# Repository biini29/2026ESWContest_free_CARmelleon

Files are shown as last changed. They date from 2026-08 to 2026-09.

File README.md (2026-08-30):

# Smart Seat (Family Care) 🚗💺

> A ROS 2-based adaptive car seat system that automatically reshapes the backrest curve and adjusts seatbelt height to fit each occupant — from pregnant passengers to children old enough to have outgrown a car seat, to guests — sharing a single family vehicle.

**Embedded SW Contest 2026 — 자유공모 (Free Topic)** | Team **CAR멜레온**, Dongguk University, Dept. of Mechanical, Robot & Energy Engineering

**Team**
| Name | Role |
|---|---|
| **Sulbeen Min** (민설빈, Team Leader) | ROS 2 system integration, control logic, hardware bridge, calibration, Size Korea regression analysis |
| **Jaekyung Kim** (김재경) | Overall design & pin wiring, integrating existing nodes into the launch file, GitHub repository organization |
| **Bogyeom Cha** (차보겸) | Overall design (lead) & hardware wiring, assembly integration, GitHub repository organization |

> Full background, goals, usage scenarios, team role breakdown, and the complete development schedule are in [`docs/01_Project_Overview/`](./docs/01_Project_Overview/).

---

## 📂 소스코드 위치 (심사용 바로가기)

| 구분 | 경로 | 설명 |
|---|---|---|
| ROS 2 노드 (Python) | [`src/`](./src/) | 키패드·프로필 계산·시트/벨트 제어·아두이노 브릿지 5개 노드 |
| 아두이노 스케치 (C++) | [`arduino/smart_seat_mega/`](./arduino/smart_seat_mega/) | 리니어 액추에이터 5개 구동 + HC-SR04 초음파 측정 |
| 커스텀 메시지 | [`msg/TargetSeatProfile.msg`](./msg/TargetSeatProfile.msg) | 벨트 높이 + 액추에이터 목표 배열 |
| 실행 파일 | [`launch/smart_seat.launch.py`](./launch/smart_seat.launch.py) | 노드 5개 일괄 실행 |
| 데이터 | [`profiles.json`](./profiles.json), [`belt_home.json`](./belt_home.json) | 가족 프로필 · 다이나믹셀 홈 위치 |

> 데이터 흐름: `keypad_node → /body_data → profile_inference_node → /target_seat_profile → seat_controller_node / belt_controller_node → /motor_cmd → arduino_bridge_node`
> 초음파는 아두이노가 측정 → `arduino_bridge_node`가 `/ultrasonic_distance`로 중계 → `keypad_node` 수신.

---

## 📌 Overview

Smart Seat infers a rider's body profile — from height, weight, and pregnancy status — using an anthropometric regression model built on **Size Korea 8th survey data (n=5,092)**, then drives:

- **5 linear actuators** to reshape the backrest along a Gaussian curve centered on the lumbar apex (with a softened, lower curve for pregnant riders, based on ergonomics literature on lordosis and iliac artery compression risk), and
- **2 Dynamixel servo motors** to raise or lower the seatbelt anchor to shoulder height (or pelvic height in pregnant mode).

Riders select a saved family profile (A/B/C) or enter a custom height as a guest, via a 4×4 keypad + I2C LCD — or simply sit still for 3 seconds (long-press the guest key) and let an ultrasonic sensor estimate their height automatically. The whole pipeline — input → body model → actuator targets → motor motion — runs as a set of ROS 2 nodes on a Raspberry Pi, bridging to an Arduino Mega (linear actuators) and a U2D2 Power Hub Board (Dynamixel belt motors).

> 📖 더 자세한 문서는 [`docs/`](./docs/) 폴더를 참고하세요 — [프로젝트 개요](./docs/01_Project_Overview/), [설계](./docs/02_Design/), [하드웨어 부품 목록](./docs/03_Hardware/), [소프트웨어 아키텍처](./docs/04_Software/), [테스트 로그](./docs/05_Test/), [데모 자료](./docs/06_Demo/).

<!-- IMAGE: hero shot — 완성된 시트 전체 모습 (또는 작동 GIF), 파일명 예: docs/img/hero.jpg -->
<!-- ![Smart Seat](docs/img/hero.jpg) -->

## 📸 Image Checklist

아래 표에 해당하는 사진/영상을 찍어서 `docs/img/`(사진), `docs/cad/`(3D·2D 도면)에 넣고, 이 파일의 해당 `<!-- IMAGE -->` 주석 자리에 마크다운 이미지 태그로 바꿔주세요.

| # | 내용 | 종류 | 넣을 위치(이 파일 내) |
|---|---|---|---|
| 1 | 완성된 시트 전체 모습 (또는 작동 GIF) | 실물 사진/GIF | Overview 바로 아래 (hero) |
| 2 | 전체 조립 렌더 (등받이+벨트 결합) | 3D 렌더 | Hardware 섹션 |
| 3 | 배선 실물 사진 (아두이노·L298N·다이나믹셀·U2D2 연결부) | 실물 사진 | Hardware 섹션 |
| 4 | 키패드+LCD 클로즈업 | 실물 사진 | Hardware 섹션 |
| 5 | 리니어 액추에이터 5개 배치 클로즈업 | 실물 사진 | Hardware 섹션 |
| 6 | 벨트 릴/가이드레일 구조 | 3D 렌더 또는 실물 사진 | Hardware 섹션 |
| 7 | 헤드레스트 ㄱ자 브라켓 (초음파센서 마운트) | 3D 렌더 또는 실물 사진 | Hardware 섹션 |
| 8 | 2D 상세 도면 전체 | 2D CAD | `docs/cad/` 폴더에 파일만 넣기 (README엔 폴더 링크만) |

---

| | |
|---|---|
| **Platform** | Raspberry Pi 3 (ROS 2 Humble) + Arduino Mega |
| **Actuation** | 5x Linear Actuators (backrest) + 2x Dynamixel XL430-W250-T (seatbelt height) |
| **Input** | 4x4 matrix keypad + I2C LCD (family profiles + guest mode) |
| **Language** | Python (ROS 2 nodes), C/C++ (Arduino firmware) |
| **Communication** | ROS 2 topics · Serial/UART (Arduino) · U2D2 (Dynamixel Protocol 2.0) |

---

## 🏗️ System Architecture

```mermaid
graph LR
    K[keypad_node<br/>keypad + LCD, family profiles] -- /body_data --> P[profile_inference_node<br/>Size Korea regression + Gaussian curve]
    P -- /target_seat_profile --> S[seat_controller_node<br/>per-actuator timing control]
    P -- /target_seat_profile --> B[belt_controller_node<br/>Dynamixel position control]
    S -- /motor_cmd --> AB[arduino_bridge_node]
    AB -- Serial/UART --> AM[Arduino Mega]
    AM --> LA[5x Linear Actuators]
    B -- U2D2 / Protocol 2.0 --> DXL[2x Dynamixel XL430]
```

---

## 🧩 ROS 2 Nodes

### `profile_inference_node`
Converts height (+ weight, + pregnancy flag) into:
- a per-actuator backrest push profile, using a **Gaussian curve** centered on the lumbar apex (`sitting_height × 0.18`, or `× 0.12` and softened in pregnant mode) — modeling the cloth+foam surface as a continuous curve rather than 5 independent points, and
- a target seatbelt height (shoulder height `sitting_height × 0.80` in normal mode, a fixed pelvic target in pregnant mode), converted to Dynamixel ticks via an empirically calibrated ticks/mm ratio.

Sitting height is estimated from a linear regression fit to Size Korea 8th survey data (R² = 0.842).

### `seat_controller_node`
Drives the 5 linear actuators (no position encoders):
- Per-motor, per-direction speed constants (measured individually) convert a target displacement into a drive duration
- Threaded, simultaneous multi-actuator motion
- Reset sequence to re-home all actuators to a known baseline

### `belt_controller_node`
Drives the 2 Dynamixel seatbelt motors in **Extended Position Control Mode** (multi-turn):
- Loads a calibrated home position from `belt_home.json` and homes once at startup
- Converts target ticks (from `profile_inference_node`) into absolute Dynamixel goal positions
- Waits for actual arrival (position-stall detection) rather than a fixed timeout
- Ignores the shared reset signal — only the linear actuators reset on demand, since belt homing is comparatively slow

### `arduino_bridge_node`
Bridges ROS 2 and the embedded layer — subscribes to `/motor_cmd`, translates commands into the `M,<motor>,<dir>,<speed>` serial protocol, and forwards them to the Arduino Mega over UART.

### `keypad_node`
Scans a 4×4 matrix keypad (non-blocking), drives a 16x2 I2C LCD, and loads family profiles (name, height, pregnancy flag) from `profiles.json`. Profile buttons (A/B/C) publish a saved profile; a guest button enters free-form height entry with range validation. Long-pressing the guest button (3s) instead triggers an **ultrasonic auto-measurement**: an HC-SR04 sensor mounted above the seat measures the distance to the rider's head, converts it (via the 2:1 physical scale factor and the same Size Korea regression) into an estimated standing height, and either applies it directly or shows an out-of-range message if outside 130–185cm.

---

## 🔧 Hardware

| Component | Role |
|---|---|
| Raspberry Pi 3 | Runs ROS 2 Humble, all high-level nodes |
| Arduino Mega | Low-level PWM driving for 5 linear actuators |
| 5x Linear Actuators + L298N drivers | Backrest shape adjustment |
| 2x Dynamixel XL430-W250-T + U2D2 Power Hub Board | Seatbelt anchor height adjustment |
| 4x4 matrix keypad + I2C LCD (0x27) | Family profile selection / guest input |
| HC-SR04 ultrasonic sensor (mounted in a 3D-printed ㄱ-bracket above the seat) | Automatic height estimation on guest-key long-press |

USB device names are pinned via `udev` rules (`/dev/arduino_linear`, `/dev/belt_u2d2`) so port numbers no longer shift between reboots or reconnects.

<!-- IMAGE: 배선도(회로 사진 또는 3D 조립 렌더), 개별 하드웨어 클로즈업 — 위 Image Checklist #2~7 참고 -->
<!-- ![Wiring](docs/img/wiring.jpg) -->
<!-- ![Assembly](docs/cad/assembly_render.png) -->
<!-- 2D 상세 도면 전체는 docs/cad/ 폴더 참고 -->

---

## 🚀 How to Run

```bash
# 1. Build the workspace
cd ~/ros2_ws
colcon build --packages-select smart_seat
source install/setup.bash

# 2. Launch the full system
ros2 launch smart_seat smart_seat.launch.py

# 3. (Example) Send a body profile directly, bypassing the keypad
ros2 topic pub /body_data geometry_msgs/msg/Point "{x: 178.0, y: 65.0, z: 0.0}" --once
# x = height (cm), y = weight (kg), z = 1.0 for pregnant mode
```

---

## 🐛 Troubleshooting Log

Real problems hit and solved during development:

**Repeated stepper driver failures (NEMA17 + DRV8825)**
Symptom: driver board smoke, melted jumper wires on GND and VMOT lines, twice. Root cause never fully confirmed (suspected VREF/current-limit misconfiguration). Fix: abandoned the stepper approach entirely and switched to Dynamixel XL430 servos with a U2D2 Power Hub Board, which have built-in current limiting.

**스텝모터 구동 시 라즈베리파이 저전압 증상**
Symptom: intermittent USB dropouts, `Undervoltage detected!` in `dmesg`, occurring specifically while driving the stepper motors (NEMA17 + DRV8825). Diagnosis: not a PD-adapter/Pi incompatibility — the same adapter (PD/fixed-5V dual capable) worked fine before and after; the undervoltage coincided with the stepper motors' high current draw pulling down the shared rail. Fix: the symptom disappeared entirely once the stepper motors were replaced with Dynamixel servos — no separate power adapter swap was needed.

**Belt tick-to-mm ratio looked wildly nonlinear**
Symptom: identical tick commands produced very different real-world displacements across trials; initially suspected reel slip or layer-diameter growth from overlapping string winds. Root cause: the test script only observed motion for a fixed 4–6 second window and force-cut torque before large moves had actually finished — an artifact of the test harness, not the mechanism. Fix: rewrote the test/move scripts to wait for actual arrival (position-stall detection) instead of a fixed timeout.

**USB port numbers (`/dev/ttyUSB0/1/2`) kept shifting**
Symptom: recurring `could not open port` errors across both the Arduino and the Dynamixel U2D2 whenever a device was reconnected or the Pi rebooted. Fix: added `udev` rules keyed on each device's USB vendor/product ID and serial number, giving them fixed symlink names (`/dev/arduino_linear`, `/dev/belt_u2d2`).

**Physical motor position swap (linear actuators)**
Symptom: actuator at the 150mm (lumbar) mounting position was actually wired to Arduino motor channel 2, and vice versa for channel 1 — a wiring/assembly mix-up discovered after calibration. Fix: rather than re-wiring, added a `MOTOR_MAP` lookup in `seat_controller_node` so logical actuator positions map to the correct physical channel in software.

**Belt position drifted after repeated manual repositioning**
Symptom: after physically moving the belt motors by hand during debugging, the seat would move to unexpected/out-of-range positions on the next command. Root cause: the saved `belt_home.json` reference no longer matched the true physical home. Fix: re-homed by hand, re-captured the current raw encoder position into `belt_home.json`.

**Race condition on repeated button presses**
Symptom: pressing the same profile button (e.g., B) repeatedly sent the belt to a different position each time. Root cause: each press spawned a new thread that concurrently wrote to the same Dynamixel `GroupSyncWrite` object. Fix: added a `threading.Lock` around each belt move so commands execute strictly in sequence.

**Belt appeared to not return home after being idle for days**
Symptom: on restart after a multi-day gap, the belt controller logged a normal-looking homing sequence but the belt didn't visibly move. Root cause: Dynamixel torque had been left disabled (torque is cut on node shutdown) — the controller was correctly commanding a position, but with no torque applied the motor simply couldn't act on it. Fix: re-enabled torque before testing; confirmed homing works correctly once torque is on.

**Keypad extension cable produced spurious key presses**
Symptom: right after startup, the 'D' key would register as pressed with no one touching it, and only the rightmost column / bottom row of keys (A/B/C/D, `.`/0/E) behaved erratically while number keys were fine. Diagnosis: scanning each row while it was driven HIGH and watching for unexpected column reads (with nothing pressed) showed random, shifting ghost signals across multiple columns — consistent with a loose connection rather than a fixed miswire. Root cause: the keypad extension cable's connector was making intermittent contact. Fix: tightened the connector; the cable is kept physically undisturbed during demos as a precaution.

<!-- 개발하면서 겪는 문제들을 여기에 계속 기록하세요. -->

---

## 📄 License

This project is licensed under the [MIT License](./LICENSE).

Third-party CAD assets (Dynamixel, linear actuator, HC-SR04 vendor/community models) used under their respective licenses — see [`docs/02_Design/mechanical/3D_model/partial_component/third_party/README.md`](./docs/02_Design/mechanical/3D_model/partial_component/third_party/README.md) for full attribution.

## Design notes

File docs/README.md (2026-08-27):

# 문서 목차

가변형 스마트시트(Family Care) 프로젝트의 전체 개발 문서입니다. 아래 순서대로 읽으시면 프로젝트를 처음부터 이해할 수 있습니다.

## 📋 [01_Project_Overview](./01_Project_Overview/)
개발 배경, 목표, 사용 시나리오, 팀 구성, 전체 개발 일정을 담고 있습니다. **여기부터 읽으시는 걸 추천합니다.**

- [01_Background_and_Goal.md](./01_Project_Overview/01_Background_and_Goal.md) — 개발 배경 및 목표
- [02_System_Architecture_Overview.md](./01_Project_Overview/02_System_Architecture_Overview.md) — 전체 시스템 구성 요약
- [03_Team_Roles_and_Schedule.md](./01_Project_Overview/03_Team_Roles_and_Schedule.md) — 팀원 역할 및 개발 일정

## 🎨 [02_Design](./02_Design/)
전기·기구 설계 문서입니다.

- [electrical/](./02_Design/electrical/) — 전원 계통도, 전체 결선도, Arduino/L298N 핀맵
- [mechanical/](./02_Design/mechanical/) — 3D 모델(조립도, 부품별 CAD), third-party CAD 출처

## 🔧 [03_Hardware](./03_Hardware/)
사용한 하드웨어 부품 목록(BOM)과 실제 구매 비용을 정리했습니다.

## 💻 [04_Software](./04_Software/)
ROS 2 소프트웨어 구조와 핵심 알고리즘 문서입니다.

- [01_Ros_Architecture.md](./04_Software/01_Ros_Architecture.md) — 노드 구성, 토픽/메시지 구조
- [02_Seat_Control_Algorithm.md](./04_Software/02_Seat_Control_Algorithm.md) — 회귀식, 가우시안 곡선, 벨트 계산식
- [03_Arduino_Ros_Protocol.md](./04_Software/03_Arduino_Ros_Protocol.md) — Arduino ↔ ROS 2 시리얼 프로토콜

## 🧪 [05_Test](./05_Test/)
개발 중 발생한 장애요인과 해결방안을 정리한 트러블슈팅 로그입니다.

## 🎬 [06_Demo](./06_Demo/)
시스템 블록 다이어그램, 하드웨어 실물 사진, 시연 영상입니다.

---

## 관련 코드

- [`../src/`](../src/) — ROS 2 노드 5개 소스코드
- [`../launch/`](../launch/) — 전체 시스템 실행 launch 파일
- [`../msg/`](../msg/) — 커스텀 메시지 정의
- [`../scripts/`](../scripts/) — `keypad_node.py` 내 세 기능(게스트모드, 프로필관리, 초음파필터) 설명 문서

전체 프로젝트 개요는 저장소 최상위 [README.md](../README.md)를 참고하세요.

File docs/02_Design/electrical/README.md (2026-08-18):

# Electrical Subsystem — 개요

전원, 통신, 센서/액추에이터 배선을 다루는 전기 서브시스템 문서입니다. 상세 핀맵은 [`03_Pinout_Table.md`](./03_Pinout_Table.md), 전체 회로도는 [`전원계통도_및_전체_결선도.png`](./전원계통도_및_전체_결선도.png)를 참고하세요.

---

## 1. 전원 계통 (2개 독립 라인)

| 전원 | 대상 | 비고 |
|---|---|---|
| 5V 전원 어댑터 (다이소, 12V/5V 겸용) | Raspberry Pi 3 전용 | 12V SMPS 계통과 완전히 독립된 별도 전원선. 스텝모터 구동 중 저전압 증상이 있었으나 원인은 스텝모터 전류 소모였음(어댑터 자체 문제 아님) — 다이나믹셀 교체 후 해소 |
| 12V SMPS | L298N 드라이버 3개 + U2D2 Power Hub Board | 모터/서보 구동 전원, Pi/Arduino 로직 전원과 분리 |

**⚠️ 공통 접지(GND) 필수**: Raspberry Pi · Arduino Mega · L298N × 3 · 12V SMPS · U2D2의 GND는 모두 하나로 묶여야 합니다. 분리되어 있으면 시리얼 통신 오류나 센서 오작동의 원인이 됩니다.

---

## 2. 통신 계통

| 연결 | 방식 | 고정 장치명 | 비고 |
|---|---|---|---|
| Pi ↔ Arduino Mega | USB Serial, 115200bps | `/dev/arduino_linear` | `M,모터,방향,속도` 프로토콜 |
| Pi ↔ U2D2 | USB, Dynamixel Protocol 2.0, 1,000,000bps | `/dev/belt_u2d2` | GroupSyncWrite로 동시 제어 |
| Pi GPIO ↔ 키패드 4x4 | 폴링 방식(50ms) | — | Row 4핀 OUT, Col 4핀 IN(PUD_DOWN) |
| Pi GPIO(I2C) ↔ LCD | I2C, 주소 0x27 | — | SDA=GPIO2, SCL=GPIO3 |
| Pi GPIO ↔ HC-SR04 | TRIG/ECHO 폴링 | — | TRIG=GPIO23, ECHO=GPIO24 |

### USB 장치명이 고정된 이유

USB 재연결·재부팅마다 `/dev/ttyUSB0/1/2` 번호가 바뀌어 연결 실패가 반복되던 문제를, `udev` 규칙(장치의 USB Vendor/Product ID + 시리얼 번호 기준)으로 고정 심볼릭 링크를 부여해 해결했습니다. 코드에서는 `/dev/ttyUSB*`가 아니라 반드시 `/dev/arduino_linear`, `/dev/belt_u2d2`를 참조합니다.

---

## 3. 주의사항

### HC-SR04 ECHO 핀 레벨시프트

HC-SR04의 ECHO 출력은 5V인데, Raspberry Pi GPIO는 3.3V 입력 기준입니다. **ECHO를 GPIO에 직결하면 장기적으로 GPIO 손상 위험이 있습니다.** 저항 분배(예: 1kΩ + 2kΩ) 또는 레벨시프터를 거치는 것을 권장하며, 현재 구성에서 이 부분을 확인이 필요합니다.

### Arduino Mega 스케치 관리

Arduino에는 리니어 액추에이터 전용 스케치가 항상 올라가 있어야 합니다. 개발 중 다른 테스트 스케치를 업로드한 뒤 리니어 전용 스케치로 되돌리지 않아 전체 시스템이 응답하지 않았던 사고가 있었습니다 — 스케치를 바꿔 테스트할 경우, 작업 종료 시 반드시 리니어 전용 스케치로 재업로드해야 합니다.

### 다이나믹셀 보드레이트

기본값(57600)이 아니라 **1,000,000bps**로 설정되어 있습니다. 다른 보드레이트로는 ping조차 응답하지 않습니다.

---

## 4. 관련 문서

- [`03_Pinout_Table.md`](./03_Pinout_Table.md) — Arduino/L298N 상세 핀맵
- [`전원계통도_및_전체_결선도_통합.md`](./전원계통도_및_전체_결선도_통합.md) — 통합 회로도
- [`03_Arduino_Ros_Protocol.md`](../../04_Software/03_Arduino_Ros_Protocol.md) — 시리얼 프로토콜 명세
- [`01_하드웨어_사용_부품_목록표.md`](../../03_Hardware/01_하드웨어_사용_부품_목록표.md) — 부품 목록(BOM)

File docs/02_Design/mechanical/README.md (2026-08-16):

## 1. 전체 구조 개요

본 프로젝트는 실제 차량용 컴포트 시트 메커니즘을 검증하기 위해 제작된 **2:1 축소 스케일 프로토타입**입니다. 실물 시트의 기하학적 형상과 기계적 동작 원리를 유지하면서, 부스 전시 규격 제약과 3D 프린터 출력 가능 범위를 고려하여 외형 및 동작 스트로크 비율을 50% 축소 적용하였습니다.

이 축소 모형을 통해 5개의 리니어 액추에이터를 활용한 등받이 요추(Lumber) 제어 및 다이나믹셀 기반의 능동형 안전벨트 장력 조절 메커니즘을 소형 공간 내에서 직관적으로 검증할 수 있습니다.

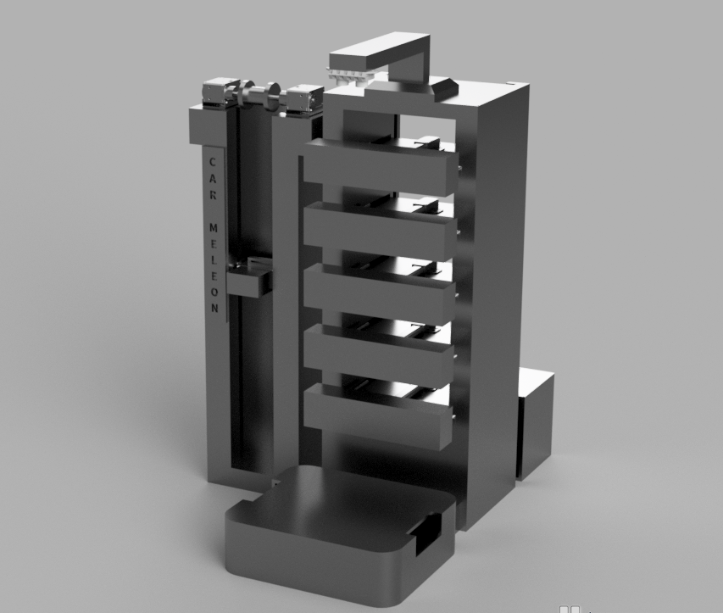
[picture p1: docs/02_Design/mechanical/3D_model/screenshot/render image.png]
전체 조립도


---

## 2. 등받이(백레스트) 구조

등받이 내부에는 총 5개의 리니어 액추에이터가 일정 간격으로 수직 배치되어 등받이 형상을 능동적으로 변형시킵니다. 액추에이터는 전용 고정 마운트 플레이트(`linear_motor_mount_plate`)에 구멍을 뚫어 나사(Screw) 체결 방식으로 고정하였으며, 백레스트 메인 외각 프레임(`backrest_outer_frame`)에 안정적으로 장착됩니다.

외부 표면은 착좌감과 실제 시트 질감을 구현하기 위해 프레임 및 액추에이터 구동부를 **천과 솜 커버**로 감싸 마감하였습니다.

- **액추에이터 결합 방식:** `linear_motor_mount_plate` 부품에 가공된 홀을 통해 리니어 액추에이터를 나사 고정
- **치수 및 간격 구현:** 
  - 하단 엉덩이 시트(시트 쿠션) 높이: **75mm**
  - 액추에이터 수직 위치: 시트 면 상단 기준 첫 번째 **160mm** 위치부터 **85mm 간격**으로 상단까지 5개 연속 배치 (160mm, 245mm, 330mm, 415mm, 500mm)
  - 각각의 액추에이터가 구동부 쉘(`backrest_shell`)을 인출/인입하여 세밀한 요추 지지 곡면 형성
- **연결 폴더:** [`Linear Moter Lumber Structure/`](./Linear%20Moter%20Lumber%20Structure/) 내부 자료 참고

| 항목 | 값 |
|---|---|
| 프레임 재질 | 3D 프린팅 및 메인 구조 프레임 |
| 액추에이터 고정 방식 | 마운트 플레이트(`linear_motor_mount_plate`) 타공 후 나사 체결 고정 |
| 등받이 곡면 재질 | 커스텀 프린팅 쉘 패널 (`backrest_shell`) + 천 & 솜 완충 커버 |

---

## 3. 안전벨트 릴/가이드레일 구조

탑승자의 체형 및 시트 상태 변형에 반응하여 벨트 장력을 능동적으로 제어하기 위해 2개의 ROBOTIS DYNAMIXEL XL430 모터가 적용되었습니다.

- **릴 메커니즘:** 다이나믹셀 모터의 출력 토크가 직접 설계한 커플링 부품인 **모터-샤프트 커넥터(`motor-shaft connecter`)** 및 **구동 샤프트(`belt_drive_shaft`)**를 거쳐 벨트 릴(`belt_drive_reel`)로 전달되어 회전하며 벨트(`belt`)를 정밀하게 권취/인출합니다.
- **주요 부품 구성:**
  - 모터 고정: `belt_motor_bracket`
  - 동력 전달 커스텀 설계: `belt_drive_shaft`, `motor-shaft connecter`
  - 벨트 가이드: `belt_guide` (벨트의 꼬임 방지 및 이송 경로 유지)
  - 외각 프레임: `seatbelt_outer_frame`
---

## 4. 헤드레스트 자리 — 초음파센서 ㄱ자 브라켓

탑승자의 앉은키(신장)를 실시간으로 측정하여 최적의 헤드레스트 위치 및 시트 제어 알고리즘을 수행하기 위해 초음파 센서(HC-SR04)가 설치됩니다.

- **설계 의도:** 센서를 상단에 안정적으로 지지하고 탑승자 머리 상단과의 거리를 수직 방향으로 정밀 측정하기 위한 ㄱ자 형상 브라켓 (`ultrasonic_sensor_bracket`) 활용
- **정확한 치수 연산:**
  - 센서 설치 높이: 바닥면 기준 프레임 높이 585mm + 브라켓 홀더 높이 80mm - 브라켓 오프셋 20mm= 645mm
  - 방석 기준 오차 보정 높이: **방석 면 기준 570mm** 고정 (상세 내용은 [`Seat_Control_Algorithm.md`](../../04_Software/Seat_Control_Algorithm.md) 4절 참고)
- **부품 위치:**
  - 센서 고정 프레임: [`ultrasonic_sensor_holder_frame.step`](3D_model/partial_component/custom/custom_stp/ultrasonic_sensor_holder_frame.step)
  - 센서 브라켓: [`ultrasonic_sensor_bracket.step`](3D_model/partial_component/third_party/third_party_stp/ultrasonic_sensor_bracket.step)

---

## 5. 파일 목록

| 파일/폴더 경로 | 설명 | 주요 포함 파일 형식 |
|---|---|---|
| [`3D_model/assemble/`](3D_model/assemble/) | 전체 조립 3D 모델 파일 | `.step`, `.stl` |
| [`3D_model/partial_component/custom/`](3D_model/partial_component/custom/) | 자체 설계 커스텀 파트 모음 | `custom_stp/` (`.step`), `custom_stl/` (`.stl`) |
| [`3D_model/partial_component/third_party/`](3D_model/partial_component/third_party/) | 외부 제조사 및 오픈소스 CAD 데이터 | `third_party_stp/` (`.step`), `third_party_stl/` (`.stl`) |
| [`3D_model/screenshot/`](3D_model/screenshot/) | 모델링 설계 및 렌더링 이미지 | `.png` |
| [`Linear Moter Lumber Structure/`](Linear%20Moter%20Lumber%20Structure/) | 등받이 액추에이터 배치 상세 구조 | - |

---

## 6. 설계 시 고려한 제약사항

- **2:1 스케일로 인한 제약 및 해결:**
  - 모터 및 액추에이터 등 기성 상용 부품은 50% 축소가 불가능하므로, 전용 마운트 플레이트(`linear_motor_mount_plate`) 및 모터 커넥터를 별도 설계하여 내부 간섭을 해결하고 메커니즘을 소형 프레임 안에 매립.
- **전시 부스 규격 (2m × 2m):**
  - 2:1 축소 설계를 통해 제어 박스(`control_box`) 포함 전체 모형이 소형화되어 2m × 2m 전시 공간 내에 여유 있게 배치 가능.
- **운반 및 조립 편의성:**
  - 시트 하단(`seat_bottom`), 백레스트 외각 프레임(`backrest_outer_frame`), 안전벨트 외각 프레임(`seatbelt_outer_frame`), 제어 박스(`control_box`)가 각 모듈별로 독립 분리 가능하도록 설계되어 있어 운반 및 현장 재조립이 용이함.

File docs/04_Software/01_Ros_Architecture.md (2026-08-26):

# ROS 2 Architecture

Smart Seat (Family Care)의 ROS 2 노드 구성, 토픽 흐름, 메시지 정의, 설계 결정을 정리한 문서입니다.

---

## 1. 노드 구성 개요

총 5개 노드가 하나의 launch 파일(`smart_seat.launch.py`)로 동시 실행됩니다.

| 노드 | 파일 | 역할 |
|---|---|---|
| `keypad_node` | `keypad_node.py` | 4x4 키패드 스캔, I2C LCD 출력, 가족 프로필 관리, 초음파 자동측정 |
| `profile_inference_node` | `profile_inference_node.py` | Size Korea 회귀식 + 가우시안 곡선 계산, 벨트 목표 산출 |
| `seat_controller_node` | `seat_controller_node.py` | 리니어 액추에이터 5개 시간기반 구동 |
| `belt_controller_node` | `belt_controller_node.py` | 다이나믹셀 2개 포지션 제어 |
| `arduino_bridge_node` | `arduino_bridge_node.py` | ROS 2 ↔ 아두이노 시리얼 브릿지 |

> **참고**: `sensor_bridge_node.py`는 압력센서(FSR) 등 실시간 피드백 확장을 위해 마련해둔 뼈대 코드로, 현재 launch 구성(5개 노드)에는 포함되지 않습니다. 향후 주행 중 자세 모니터링 등 확장 기능 개발 시 활용할 예정입니다.

---

## 2. 시스템 아키텍처 다이어그램

```mermaid
graph LR
    K[keypad_node] -- /body_data --> P[profile_inference_node]
    P -- /target_seat_profile --> S[seat_controller_node]
    P -- /target_seat_profile --> B[belt_controller_node]
    S -- /motor_cmd --> AB[arduino_bridge_node]
    AB -- "Serial (/dev/arduino_linear, 115200bps)" --> AM[Arduino Mega]
    AM --> LA[5x Linear Actuators via L298N x3]
    B -- "U2D2 (/dev/belt_u2d2, Protocol 2.0)" --> DXL[2x Dynamixel XL430]
```

---

## 3. 토픽 / 메시지 정리

| 토픽 | 메시지 타입 | 발행 | 구독 | 설명 |
|---|---|---|---|---|
| `/body_data` | `geometry_msgs/Point` | `keypad_node` | `profile_inference_node` | x=키(cm), y=몸무게(kg, 고정 65), z=임산부여부(0/1) |
| `/target_seat_profile` | `smart_seat/TargetSeatProfile` (커스텀) | `profile_inference_node` | `seat_controller_node`, `belt_controller_node` | 등받이 목표(actuator_mm[]) + 벨트 목표(belt_height_cm, 실제로는 필요틱수) |
| `/motor_cmd` | `std_msgs/String` | `seat_controller_node` | `arduino_bridge_node` | `M,모터번호,방향,속도` 형식 문자열 |

### `TargetSeatProfile.msg`

```
float32 belt_height_cm     # 벨트 필요 틱수 (필드명은 유지, 실제 단위는 틱)
float32[] actuator_mm      # 액추에이터 5개 목표 밀기량(mm)
```

- 리셋 신호는 `actuator_mm`의 모든 값이 0 이하일 때로 판단 (`belt_controller_node`는 이 신호를 무시하고 `seat_controller_node`만 반응)

---

## 4. 노드별 상세

### `keypad_node`
- 4x4 매트릭스 키패드(GPIO 폴링, 50ms 주기), I2C LCD(0x27)
- `profiles.json`에서 가족 프로필(A/B/C: 이름·키·임산부여부) 로드
- A/B/C: 저장된 프로필 즉시 적용
- D 짧게: 게스트 모드(숫자 직접입력)
- D 3초 롱프레스: 초음파 자동측정 모드
- `.`: 평상시 리셋 / 게스트모드 중 입력 없을 때 리셋+탈출 / 입력 중일 때 소수점
- 소프트웨어 안전장치: 4연속 디바운스, 다중 키 동시감지 시 무시(유령신호 방지), 부팅 1.5초 워밍업 무시구간, 게스트모드 오진입 시 프로필키 입력으로 자동 복구

### `profile_inference_node`
- Size Korea 8차 회귀식으로 앉은키 추정
- 가우시안 곡선으로 5개 액추에이터 각각의 밀기량 계산 (요추 곡선 + 헤드서포트, 둘 중 큰 값 채택)
- 벨트 목표(어깨/골반) 계산 후 2:1 스케일 + 실측 보정 적용, 틱수로 변환

### `seat_controller_node`
- 위치 센서 없음 → 모터별/방향별 실측 속도로 구동 시간 역산
- `MOTOR_MAP`으로 물리적으로 뒤바뀐 1·2번 액추에이터를 소프트웨어에서 보정
- 리셋 시 가장 오래 걸리는 모터 기준 + 여유시간만큼 전체 후진, 2번 모터만 추가 후진

### `belt_controller_node`
- Extended Position Control Mode(다회전)로 다이나믹셀 2개 구동
- `belt_home.json`에서 홈 포지션 로드, 노드 시작 시 1회 자동 홈 복귀
- 목표 도착까지 대기(포지션 스톨 감지) — 고정 타임아웃 방식은 재현성 문제로 폐기됨
- `threading.Lock`으로 동시 명령 충돌 방지 (연타 시 Race Condition 해결)
- 리셋 신호 무시 (벨트 리셋은 느려서 매번 반응하지 않음)

### `arduino_bridge_node`
- `/motor_cmd` 구독, `M,모터,방향,속도` 프로토콜로 변환하여 시리얼 전송

---

## 5. 설계 결정 근거

- **커스텀 메시지(`TargetSeatProfile`) 사용 이유**: 등받이(연속값 배열)와 벨트(단일값)를 한 번에 묶어 전달, 두 컨트롤러 노드가 같은 발행 시점의 목표를 일관되게 받도록 함
- **리셋 신호를 별도 토픽이 아닌 `/target_seat_profile`의 특수값(0 이하)으로 처리**: 새 토픽/서비스를 추가하지 않고 기존 파이프라인 재사용
- **벨트와 등받이 리셋 정책을 분리**: 벨트 홈 복귀가 상대적으로 느려, 매 리셋마다 실행하면 사용성이 떨어짐 — 노드 시작 시 1회만 자동 수행
- **USB 장치 이름 고정(`/dev/arduino_linear`, `/dev/belt_u2d2`)**: `udev` 규칙으로 포트 번호 유동성 문제 해결, 코드에서 하드코딩된 경로 안정성 확보



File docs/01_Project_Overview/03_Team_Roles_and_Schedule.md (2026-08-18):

# 팀원 역할 및 일정

## 1. 팀 구성

**팀명**: CAR멜레온 | 동국대학교 기계로봇에너지공학과

| 이름 | 역할 |
|---|---|
| **민설빈** (팀장) | ROS 2 시스템 통합, 제어 로직, 하드웨어 브릿지, 캘리브레이션, Size Korea 회귀분석 |
| **김재경** | 전체 설계 및 핀 연결, 기존 노드들을 launch 파일로 통합, GitHub 저장소 정리 |
| **차보겸** | 전체 설계(주도) 및 하드웨어 연결, 어셈블(통합) 파일 작업, GitHub 저장소 정리 |

## 2. 역할 분담 개요

- **하드웨어/메커니즘 설계**: 시트 구조, 리니어 액추에이터 배치, 다이나믹셀 벨트 릴 구조, 헤드레스트 자리 초음파센서 브라켓 CAD (주로 차보겸, 전체 설계 참여)
- **회로/전원 설계**: SMPS 배선, Arduino 핀맵, L298N 모터드라이버 회로 (김재경·차보겸 공동)
- **임베디드/ROS 소프트웨어**: 아두이노 펌웨어, ROS 2 노드, 통신 프로토콜, 캘리브레이션 (민설빈 중심)

## 3. 개발 일정

| 기간 | 단계 | 개발 내용 |
|---|---|---|
| 6/12 ~ 6/17 | 기획 | 아이디어 회의 |
| 6/18 ~ 6/20 | 기획 | 아이디어 구체화 및 개발 방향 수립 |
| 6/21 ~ 6/22 | 기획 | 주요 기능 선정 |
| 6/23 ~ 6/25 | 기획 | 개발 태스크 세분화 |
| 6/25 ~ 6/26 | 기획 | 개발계획서 작성 |
| 6/27 ~ 6/28 | 시스템 설계 | 전체 시스템 구성 설계 |
| 6/28 ~ 6/29 | 시스템 설계 | Raspberry Pi / Arduino 역할 분담 |
| 6/29 | 시스템 설계 | 사용 부품 선정 및 사양 조사 |
| 6/30 ~ 7/1 | 하드웨어 설계 | 허리 시트 및 Arduino 핀맵 설계 |
| 7/1 ~ 7/2 | 통신 설계 | Raspberry Pi-Arduino 통신 구성 |
| 7/2 ~ 7/4 | 제어 설계 | 실시간 피드백 제어 구조 확정 및 실측 회귀계수 반영 |
| 7/4 ~ 7/9 | 기구 개발 | 허리 시트 실물 출력 및 벨트 부분 설계 |
| 7/4 ~ 7/9 | ROS 2 개발 | ROS 2 노드 기본 구조 구현 |
| 7/10 ~ 7/14 | Arduino 개발 | Arduino 모터 제어 코드 작성 |
| 7/10 ~ 7/14 | 테스트 | 리니어 모터 개별 동작 테스트 |
| 7/14 ~ 7/15 | ROS 2 개발 | `/motor_cmd` 통신 구현 |
| 7/14 ~ 7/15 | ROS 2 개발 | ROS 2 Launch 통합 |
| 7/15 ~ 7/17 | ROS 2 개발 | 키패드 노드 구현 및 기능 완성 |
| 7/15 ~ 7/17 | Arduino 개발 | 벨트 구동 제어 코드 구현 |
| 7/18 ~ 7/19 | 하드웨어 개발 | LCD I2C 연결 및 동작 테스트 |
| 7/19 ~ 7/23 | 하드웨어 보완 | 하드웨어 구성 마무리 및 벨트 구동 모터 변경 |
| 7/24 ~ 7/25 | Arduino 개발 | 모터 변경에 따른 제어 코드 수정 |
| 7/25 ~ 7/27 | 시스템 통합 | 전체 하드웨어 및 ROS 2 시스템 통합 |
| 7/27 ~ 7/28 | 기능 추가 | 외관 정리 및 초음파 센서 기능 추가 |
| 7/28 ~ 7/29 | 테스트 | 실제 시트에서 리니어 모터 구동 테스트 |
| 7/29 ~ 7/30 | 검증 | 오류 및 안전성 테스트 |
| 7/31 ~ 8/3 | 개선 | 문제점 수정 및 시스템 성능 개선 |
| 8/4 ~ 8/6 | 검증 | 최종 통합 테스트 및 기능 검증 |
| 8/8 ~ 8/12 | 문서화 | GitHub 문서 및 개발 산출물 정리 |
| 8/14 ~ 8/19 | 발표 | 최종 시연 및 발표 준비 |

개발 일정 간트차트

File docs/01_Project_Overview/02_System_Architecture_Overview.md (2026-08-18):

# 전체 시스템 구성 요약

## 1. HW/SW 스택 요약

| 구분 | 구성 |
|---|---|
| 상위 제어기 | Raspberry Pi 3 (ROS 2 Humble) |
| 하위 제어기 | Arduino Mega |
| 프레임워크 | ROS 2 Humble, rclpy(Python) |
| 등받이 구동 | 리니어 액추에이터 5개 + L298N 드라이버 3개 |
| 안전벨트 구동 | Dynamixel XL430-W250-T 2개 + U2D2 Power Hub Board |
| 입력 | 4x4 매트릭스 키패드, HC-SR04 초음파 센서 |
| 출력 | I2C LCD 16x2 |
| 전원 | 12V SMPS(모터 계통), 12V/5V 겸용 어댑터(라즈베리파이 전용, 완전 독립 계통) |
| 통신 | USB Serial(Pi↔Arduino, 115200bps), USB(Pi↔U2D2, Dynamixel Protocol 2.0, 1,000,000bps), GPIO(키패드/LCD/초음파) |

상세 부품 목록은 [`03_Hardware/01_하드웨어_사용_부품_목록표.md`](../../03_Hardware/01_하드웨어_사용_부품_목록표.md) 참고.

## 2. 상위/하위 제어기 역할 분담

### Raspberry Pi (상위 제어기)
- ROS 2 노드 5개 전체 실행 (`keypad_node`, `profile_inference_node`, `seat_controller_node`, `belt_controller_node`, `arduino_bridge_node`)
- 체형 데이터 계산(회귀식, 가우시안 곡선)
- 키패드/LCD/초음파 센서 직접 제어 (GPIO)
- 다이나믹셀 직접 제어 (U2D2를 통한 Protocol 2.0 통신)
- Arduino에 시리얼로 모터 명령 전달

### Arduino Mega (하위 제어기)
- Raspberry Pi로부터 받은 `M,모터번호,방향,속도` 명령을 해석
- L298N 드라이버 3개를 통해 리니어 액추에이터 5개의 PWM 속도·방향 직접 제어
- 위치 피드백 센서가 없어, 모터별 실측 속도(mm/s) 기반 시간 제어로 위치를 추정

> 다이나믹셀(안전벨트)은 Arduino를 거치지 않고 Raspberry Pi가 U2D2를 통해 직접 제어한다 — 등받이(리니어)와 벨트(다이나믹셀)는 완전히 분리된 두 개의 구동 경로다.

## 3. 데이터 흐름 개요

```
입력(키패드/초음파) → 체형 데이터 계산 → 목표값 산출
                                              ├─→ 등받이 구동 (Pi → Arduino → L298N → 액추에이터5개)
                                              └─→ 벨트 구동 (Pi → U2D2 → 다이나믹셀2개)
```

더 상세한 노드/토픽 구조는 [`04_Software/01_Ros_Architecture.md`](../../04_Software/01_Ros_Architecture.md), 계산 알고리즘은 [`04_Software/02_Seat_Control_Algorithm.md`](../../04_Software/02_Seat_Control_Algorithm.md) 참고.

## 4. 상위 개념도

전체 기능 블록 흐름은 [`06_Demo/01_System_Block_Diagram.md`](../../06_Demo/01_System_Block_Diagram.md), 전기적 배선/전원 계통은 [`electrical/`](../electrical/) 폴더 참고.

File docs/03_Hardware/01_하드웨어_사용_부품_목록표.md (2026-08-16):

# 하드웨어 사용 부품 목록표 (BOM)

## 1. 컴퓨팅 / 제어

| 부품 | 수량 | 역할 | 구매처 | 단가 | 비고 |
|---|---|---|---|---|---|
| Raspberry Pi 3 | 1 | 메인 컨트롤러, ROS 2 Humble 실행 | 동국대 기계로봇에너지공학과 소모임 MAC 비품 | - | 5V 고정 전원 필요(PD 어댑터 비호환) |
| Arduino Mega | 1 | 리니어 액추에이터 저수준 제어 | 쿠팡 | 20,240원 | USB로 Pi와 연결 |

## 2. 등받이(리니어 액추에이터) 계열

| 부품 | 수량 | 역할 | 구매처 | 단가 | 비고 |
|---|---|---|---|---|---|
| 12V 리니어 액추에이터 | 5 | 등받이 형상 조절 (150/320/490/660/830mm 위치) | 알리익스프레스 | 25,300원 × 5 = 126,500원 | 스트로크 100mm, 부하 70N, 원격제어용 브래킷 포함 |
| L298N 모터 드라이버 | 3 | 액추에이터 5개 구동 (2+2+1) | 동국대 기계로봇에너지공학과 소모임 MAC 비품 | - | 3번 보드 B채널 미사용 |

## 3. 안전벨트(다이나믹셀) 계열

| 부품 | 수량 | 역할 | 구매처 | 단가 | 비고 |
|---|---|---|---|---|---|
| Dynamixel XL430-W250-T | 2 | 안전벨트 높이 조절 | 동국대 기계로봇에너지공학과 소모임 MAC 비품 | - | ID 2, 12 |
| U2D2 | 1 | Dynamixel ↔ USB 통신 컨버터 | 동국대 기계로봇에너지공학과 소모임 MAC 비품 | - | Protocol 2.0, 1,000,000bps |
| U2D2 Power Hub Board | 1 | Dynamixel 전원 분배 | 동국대 기계로봇에너지공학과 소모임 MAC 비품 | - | 12V 입력 |
| 웨이빙끈(이중직 30mm) | 1 | 안전벨트 본체 | 쿠팡 | 6,200원 | 릴에 감기는 벨트 재질 |
| 안전벨트 연장 클립 | 1 | 벨트 길이 조절/연결 | 쿠팡 | 3,000원 | |

## 4. 입력 / 출력

| 부품 | 수량 | 역할 | 구매처 | 단가 | 비고 |
|---|---|---|---|---|---|
| 4x4 매트릭스 키패드 | 1 | 가족 프로필 선택 / 게스트 입력 | 동국대 기계로봇에너지공학과 소모임 MAC 비품 | - | GPIO 폴링 |
| I2C LCD 16x2 | 1 | 상태 표시 | 동국대 기계로봇에너지공학과 소모임 MAC 비품 | - | PCF8574 백팩, 주소 0x27 |
| HC-SR04 초음파 센서 | 1 | 게스트 자동 신장 측정 | 동국대 기계로봇에너지공학과 소모임 MAC 비품 | - | TRIG=GPIO23, ECHO=GPIO24 |
| 저항(레벨시프트용) | - | HC-SR04 ECHO 5V→3.3V 전압분배 | 아두이노 스타터 키트 동봉품 | - | 브레드보드로 결선 |
| 브레드보드 | 1 | 저항/점퍼선 임시 결선 | 아두이노 스타터 키트 동봉품 | - | |

## 5. 전원

| 부품 | 수량 | 역할 | 구매처 | 단가 | 비고 |
|---|---|---|---|---|---|
| 전원 어댑터 (PD/고정 5V 겸용) | 1 | Raspberry Pi 전원 | 기존 보유 | - | 스텝모터 사용 시 저전압 증상 있었으나, 다이나믹셀 교체 후 문제없이 사용 중 (교체한 것 아님) |
| 12V SMPS | 1 | L298N ×3, U2D2 Power Hub 전원 | 쿠팡 | 21,000원 | 산업용 SMPS, HS 150W-12V (정격전류 약 12.5A) |
| 탈피 전원선 파워코드 케이블(3C) | 1 | SMPS 전원 입력선 | 쿠팡 | 6,200원 | |

## 6. 구조물

| 부품 | 수량 | 역할 | 구매처 | 단가 | 비고 |
|---|---|---|---|---|---|
| ㄱ자 브라켓 (3D 프린트) | 1 | 초음파 센서 하향 장착 | 자체 제작 | - | Bambu Lab PLA 필라멘트, 바닥 585mm+브라켓 60mm 위치 |
| 아크릴판 | 1 | 구조 보강/마운트 | 쿠팡 | 4,900원 | |
| 2:1 축소 모형 프레임 | 1 | 등받이/시트 기구 구조 | 자체 제작 | - | `mechanical/` 폴더 도면 참고 |

## 7. 배선 / 기타

| 부품 | 역할 | 구매처 | 비고 |
|---|---|---|---|
| USB 케이블 (Pi↔Arduino, Pi↔U2D2) | 데이터 통신 | - | udev로 `/dev/arduino_linear`, `/dev/belt_u2d2` 고정 |
| USB-A 포트 연결 케이블 | Pi 데이터/전원 연결 | 다이소 | 2,000원 |
| USB 포트 어댑터 | 포트 확장/변환 | 다이소 | 5,000원 |
| 점퍼선 일체 | GPIO/전원 배선 | 아두이노 스타터 키트 동봉품 | 모든 GND 공통 연결 필수 |
| 키패드 연장 케이블 | 키패드↔Pi 거리 확보 | - | 접촉 불량 이슈 있었음 — 커넥터 고정 상태 정기 점검 필요 |

---

## 구매 비용 요약

| 구분 | 금액 |
|---|---|
| 실구매 총액 (알리+쿠팡+다이소) | **195,040원** |
| 소모임(MAC) 비품 활용분 | 별도 구매 없음 (라즈베리파이, 다이나믹셀, U2D2, L298N, 키패드, LCD, HC-SR04 등 핵심 모듈 다수) |

> 스텝모터(NEMA17+DRV8825) 관련 자재는 소손 사고 이후 다이나믹셀로 전면 교체되어, 실제 사용 부품에서 제외했습니다. (자세한 경위는 `05_Test.md` 1번 항목 참고)

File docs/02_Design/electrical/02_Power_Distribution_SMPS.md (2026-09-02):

# Smart Seat System Power Distribution

본 문서는 스마트 시트 시스템의 전원 공급 및 분배 구조를 정리한다.

장치 간 물리적 연결은 `01_Wiring_Diagram.md`, GPIO 및 Arduino 제어 핀 정보는 `03_Pinout_Table.md`에서 관리한다.

---

## 1. 전체 전원 계통

스마트 시트 시스템의 전원은 크게 다음 3개의 계통으로 구성한다.

1. Raspberry Pi / 제어 계통
2. Linear Motor 구동 계통
3. DYNAMIXEL 구동 계통

```mermaid
flowchart TB

    P5["5V 전원"]
    PI["Raspberry Pi 3"]
    ARD["Arduino Mega 2560"]
    EXT["Arduino 확장보드"]
    US["HC-SR04"]

    SMPS["12V SMPS"]

    L1["L298N #1"]
    L2["L298N #2"]
    L3["L298N #3"]

    M1["Linear Motor 1"]
    M2["Linear Motor 2"]
    M3["Linear Motor 3"]
    M4["Linear Motor 4"]
    M5["Linear Motor 5"]

    DXP["DYNAMIXEL용<br/>별도 외부 전원"]
    HUB["U2D2 Power Hub"]

    DX1["DYNAMIXEL XL430-W250-T #1"]
    DX2["DYNAMIXEL XL430-W250-T #2"]

    P5 -->|"5V"| PI

    PI -->|"USB"| ARD
    ARD --> EXT
    EXT -->|"5V / GND"| US

    SMPS -->|"12V + GND"| L1
    SMPS -->|"12V + GND"| L2
    SMPS -->|"12V + GND"| L3

    L1 --> M1

    L2 --> M3
    L2 --> M4

    L3 --> M5
    L3 --> M2

    DXP --> HUB

    HUB --> DX1
    HUB --> DX2
```

> U2D2는 DYNAMIXEL 통신 인터페이스이므로 위 전원 흐름도에서는 구동 전원 계통과 분리하였다. U2D2의 실제 통신 결선은 `01_Wiring_Diagram.md`에서 관리한다.

---

## 2. 전원 계통 구분

```text
[1] Raspberry Pi / 제어 계통

5V 전원
   │
   ▼
Raspberry Pi 3
   │
   └── USB ──→ Arduino Mega 2560
                    │
                    ▼
              Arduino 확장보드
                    │
                    └──→ HC-SR04

[2] Linear Motor 구동 계통

12V SMPS
   │
   ├──→ L298N #1 ──→ Motor 1
   │
   ├──→ L298N #2 ──→ Motor 3 / Motor 4
   │
   └──→ L298N #3 ──→ Motor 5 / Motor 2

[3] DYNAMIXEL 구동 계통

DYNAMIXEL용 별도 외부 전원
              │
              ▼
       U2D2 Power Hub
          │        │
          ▼        ▼
    DYNAMIXEL #1  DYNAMIXEL #2
```

---

## 3. Raspberry Pi 3 전원 계통

Raspberry Pi 3는 별도의 5V 전원을 사용한다.

본 시스템에서는 12V → 5V DC-DC 컨버터를 사용하지 않는다.

```text
5V 전원
   │
   ▼
Raspberry Pi 3
```

Raspberry Pi 3는 시스템의 메인 컨트롤러로 사용한다.

---

## 4. Arduino Mega 2560 전원

Arduino Mega 2560은 Raspberry Pi 3와 USB로 연결한다.

```text
5V 전원
   │
   ▼
Raspberry Pi 3
   │
   │ USB
   ▼
Arduino Mega 2560
```

USB 연결은 다음 두 가지 역할을 한다.

- Raspberry Pi ↔ Arduino Serial 통신
- Arduino 로직 전원 공급

Linear Motor의 구동 전원은 Arduino에서 공급하지 않는다.

---

## 5. Arduino 확장보드 및 HC-SR04 전원

Arduino Mega 2560에 장착된 확장보드를 통해 HC-SR04를 연결한다.

```text
Arduino Mega 2560
        │
        ▼
  Arduino 확장보드
        │
        │ 5V / GND
        ▼
     HC-SR04
```

HC-SR04는 Arduino 계통의 5V와 GND를 사용한다.

별도의 12V 구동 전원은 사용하지 않는다.

---

## 6. 12V SMPS 전원 분배

Linear Motor 5개의 구동 전원은 12V SMPS에서 공급한다.

SMPS의 +12V와 GND를 3개의 L298N Motor Driver에 분배한다.

```text
                       12V SMPS
                          │
                    +12V / GND
                          │
              ┌───────────┼───────────┐
              │           │           │
              ▼           ▼           ▼
          L298N #1    L298N #2    L298N #3
```

Arduino는 L298N에 제어 신호만 전달하며, 실제 Linear Motor의 구동 전력은 12V SMPS에서 공급한다.

---

## 7. L298N #1 전원 계통

L298N #1은 12V SMPS에서 전원을 공급받아 Linear Motor 1을 구동한다.

```text
12V SMPS
   │
   │ 12V + GND
   ▼
L298N #1
   │
   ▼
Motor 1
```

---

## 8. L298N #2 전원 계통

L298N #2는 12V SMPS에서 전원을 공급받아 Linear Motor 3과 Motor 4를 구동한다.

```text
             12V SMPS
                │
                │ 12V + GND
                ▼
            L298N #2
             │     │
             ▼     ▼
         Motor 3  Motor 4
```

---

## 9. L298N #3 전원 계통

L298N #3은 12V SMPS에서 전원을 공급받아 Linear Motor 5와 Motor 2를 구동한다.

```text
             12V SMPS
                │
                │ 12V + GND
                ▼
            L298N #3
             │     │
             ▼     ▼
         Motor 5  Motor 2
```

---

## 10. Linear Motor 전체 전원 분배

```text
                         12V SMPS
                            │
                      +12V / GND
                            │
                 ┌──────────┼──────────┐
                 │          │          │
                 ▼          ▼          ▼
             L298N #1   L298N #2   L298N #3
                 │        │   │       │   │
                 ▼        ▼   ▼       ▼   ▼
              Motor 1  Motor 3 4   Motor 5 2
```

### 전원 분배 요약

| 전원 공급원 | Motor Driver | 연결 Motor |
|---|---|---|
| 12V SMPS | L298N #1 | Motor 1 |
| 12V SMPS | L298N #2 | Motor 3, Motor 4 |
| 12V SMPS | L298N #3 | Motor 5, Motor 2 |

---

## 11. Linear Motor 제어 전원과 구동 전원 구분

Linear Motor 계통에서는 Arduino의 제어 신호와 SMPS의 구동 전원을 구분한다.

```text
Arduino Mega 2560
        │
        │ 제어 신호
        ▼
      L298N
        ▲
        │
        │ 12V 구동 전원
        │
     12V SMPS
        │
        ▼
  Linear Motor
```

Arduino Mega는 모터를 직접 구동하지 않는다.

Arduino는 L298N에 PWM 및 방향 제어 신호를 전달하고, 실제 모터 구동에 필요한 전력은 12V SMPS에서 공급한다.

---

## 12. U2D2 계통

Raspberry Pi 3와 U2D2는 USB로 연결한다.

```text
Raspberry Pi 3
      │
      │ USB
      ▼
    U2D2
```

U2D2는 Raspberry Pi와 DYNAMIXEL 사이의 통신 인터페이스 역할을 한다.

DYNAMIXEL의 모터 구동 전원은 Raspberry Pi USB에서 공급하지 않는다.

---

## 13. U2D2 Power Hub 외부 전원

U2D2 Power Hub에는 DYNAMIXEL 구동을 위한 별도의 외부 전원 장치를 연결한다.

```text
DYNAMIXEL용 별도 외부 전원
              │
              ▼
       U2D2 Power Hub
          │        │
          ▼        ▼
    DYNAMIXEL #1  DYNAMIXEL #2
```

U2D2 Power Hub는 별도 외부 전원을 DYNAMIXEL 계통에 분배한다.

---

## 14. DYNAMIXEL 통신과 전원 구분

DYNAMIXEL 계통에서는 통신 경로와 구동 전원 경로를 구분한다.

```text
[통신 경로]

Raspberry Pi 3
      │
      │ USB
      ▼
    U2D2
      │
      │ 3핀
      ▼
U2D2 Power Hub
      │
      ├──→ DYNAMIXEL #1
      └──→ DYNAMIXEL #2

[구동 전원 경로]

별도 외부 전원
      │
      ▼
U2D2 Power Hub
      │
      ├──→ DYNAMIXEL #1
      └──→ DYNAMIXEL #2
```

즉,

- Raspberry Pi → U2D2 : 통신 인터페이스
- U2D2 → Power Hub : DYNAMIXEL 통신
- 외부 전원 → Power Hub : DYNAMIXEL 구동 전원
- Power Hub → DYNAMIXEL : 통신 및 구동 전원 전달

---

## 15. 전체 전원 흐름

```text
================================================
          Raspberry Pi / Control Power
================================================

5V 전원
   │
   ▼
Raspberry Pi 3
   │
   └── USB ──→ Arduino Mega 2560
                    │
                    └──→ HC-SR04

================================================
             Linear Motor Power
================================================

12V SMPS
   │
   ├──→ L298N #1
   │        └──→ Motor 1
   │
   ├──→ L298N #2
   │        ├──→ Motor 3
   │        └──→ Motor 4
   │
   └──→ L298N #3
            ├──→ Motor 5
            └──→ Motor 2

================================================
              DYNAMIXEL Power
================================================

별도 외부 전원
      │
      ▼
U2D2 Power Hub
      │
      ├──→ DYNAMIXEL #1
      └──→ DYNAMIXEL #2
```

---

## 16. 전체 전원 계통 요약표

| 장치 | 전원 공급원 | 공급 방식 | 용도 |
|---|---|---|---|
| Raspberry Pi 3 | 별도 5V 전원 | 직접 공급 | 메인 컨트롤러 |
| Arduino Mega 2560 | Raspberry Pi 3 | USB | Arduino 로직 전원 |
| Arduino 확장보드 | Arduino Mega | 보드 연결 | 배선 확장 |
| HC-SR04 | Arduino 계통 | 5V / GND | 센서 전원 |
| L298N #1 | 12V SMPS | 12V + GND | Motor 1 구동 |
| L298N #2 | 12V SMPS | 12V + GND | Motor 3 / 4 구동 |
| L298N #3 | 12V SMPS | 12V + GND | Motor 5 / 2 구동 |
| Motor 1 | L298N #1 | Motor Output | 구동 전원 |
| Motor 2 | L298N #3 | Motor Output | 구동 전원 |
| Motor 3 | L298N #2 | Motor Output | 구동 전원 |
| Motor 4 | L298N #2 | Motor Output | 구동 전원 |
| Motor 5 | L298N #3 | Motor Output | 구동 전원 |
| U2D2 | Raspberry Pi 3 | USB | 통신 인터페이스 |
| U2D2 Power Hub | 별도 외부 전원 | 외부 전원 입력 | DYNAMIXEL 전원 분배 |
| DYNAMIXEL #1 | U2D2 Power Hub | 3핀 | 통신 / 구동 전원 |
| DYNAMIXEL #2 | U2D2 Power Hub | 3핀 | 통신 / 구동 전원 |

---

## 17. 전원 계통 핵심 구조

```mermaid
flowchart LR

    P5["5V 전원"] --> PI["Raspberry Pi 3"]
    PI -->|"USB"| ARD["Arduino Mega 2560"]

    SMPS["12V SMPS"] --> L1["L298N #1"]
    SMPS --> L2["L298N #2"]
    SMPS --> L3["L298N #3"]

    L1 --> M1["Motor 1"]

    L2 --> M3["Motor 3"]
    L2 --> M4["Motor 4"]

    L3 --> M5["Motor 5"]
    L3 --> M2["Motor 2"]

    DXP["DYNAMIXEL용<br/>별도 외부 전원"] --> HUB["U2D2 Power Hub"]

    HUB --> DX1["DYNAMIXEL #1"]
    HUB --> DX2["DYNAMIXEL #2"]
```

---

## 18. 문서 관리 기준

```text
electric/
├── 01_Wiring_Diagram.md
├── 02_Power_Distribution_SMPS.md
└── 03_Pinout_Table.md
```

### `01_Wiring_Diagram.md`

장치 간 실제 물리적 연결 관계를 관리한다.

- Breadboard
- Arduino 확장보드
- Raspberry Pi ↔ Arduino
- Arduino ↔ HC-SR04
- Arduino ↔ L298N
- L298N ↔ Linear Motor
- Raspberry Pi ↔ U2D2
- U2D2 ↔ Power Hub ↔ DYNAMIXEL

### `02_Power_Distribution_SMPS.md`

전원 공급원과 전원 분배 경로를 관리한다.

- Raspberry Pi 5V 전원
- Arduino USB 전원
- HC-SR04 전원
- 12V SMPS
- L298N / Linear Motor 구동 전원
- U2D2 Power Hub 별도 외부 전원
- DYNAMIXEL 구동 전원

### `03_Pinout_Table.md`

실제 제어 핀 번호를 관리한다.

- Raspberry Pi GPIO
- LCD SDA / SCL
- Keypad ROW / COL
- Arduino Digital Pin
- HC-SR04 TRIG / ECHO
- L298N ENA / ENB
- L298N IN1 ~ IN4
- Motor별 제어 핀

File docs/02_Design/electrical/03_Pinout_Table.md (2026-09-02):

# Smart Seat System Pinout Table

본 문서는 실제 제작 회로 및 Cirkit Designer 회로도를 기준으로 스마트 시트 시스템의 핀 연결 정보를 정리한다.

세부 장치 연결 구조는 `01_Wiring_Diagram.md`, 전원 공급 구조는 `02_Power_Distribution_SMPS.md`에서 관리한다.

---

## 1. 시스템 구성

| 장치 | 수량 | 역할 |
|---|---:|---|
| Raspberry Pi 3 | 1 | 메인 컨트롤러 |
| Breadboard | 1 | Raspberry Pi 주변 장치 배선 |
| 4×4 Matrix Keypad | 1 | 사용자 입력 |
| I2C LCD 16×2 | 1 | 사용자 정보 및 상태 표시 |
| Arduino Mega 2560 | 1 | 센서 및 리니어 모터 제어 |
| Arduino 확장보드 | 1 | Arduino 핀 연결 및 배선 확장 |
| HC-SR04 | 1 | 거리 측정 |
| L298N Motor Driver | 3 | 리니어 모터 구동 |
| Linear Motor | 5 | 등받이 형상 조절 |
| U2D2 | 1 | Raspberry Pi ↔ DYNAMIXEL 통신 |
| U2D2 Power Hub | 1 | DYNAMIXEL 통신 및 전원 분배 |
| DYNAMIXEL XL430-W250-T | 2 | 벨트 구동 |
| 12V SMPS | 1 | Linear Motor 계통 전원 |

---

# 2. Raspberry Pi 3 Pinout

## 2-1. I2C LCD 16×2

| LCD Pin | Raspberry Pi 3 | Physical Pin | Role |
|---|---|---:|---|
| VCC | 5V | Pin 2 | LCD 전원 |
| GND | GND | Pin 6 | Ground |
| SDA | GPIO 2 | Pin 3 | I2C Data |
| SCL | GPIO 3 | Pin 5 | I2C Clock |

### I2C 설정

```text
LCD I2C Address : 0x27
```

---

## 2-2. 4×4 Matrix Keypad

| Keypad Pin | Raspberry Pi GPIO | Physical Pin |
|---|---:|---:|
| COL1 | GPIO 5 | Pin 29 |
| COL2 | GPIO 6 | Pin 31 |
| COL3 | GPIO 13 | Pin 33 |
| COL4 | GPIO 19 | Pin 35 |
| ROW1 | GPIO 26 | Pin 37 |
| ROW2 | GPIO 12 | Pin 32 |
| ROW3 | GPIO 16 | Pin 36 |
| ROW4 | GPIO 20 | Pin 38 |

### Keypad GPIO 요약

```text
COL1 → GPIO 5
COL2 → GPIO 6
COL3 → GPIO 13
COL4 → GPIO 19

ROW1 → GPIO 26
ROW2 → GPIO 12
ROW3 → GPIO 16
ROW4 → GPIO 20
```

---

# 3. Raspberry Pi 3 ↔ Arduino Mega 2560

Raspberry Pi 3와 Arduino Mega 2560은 USB로 연결한다.

| Raspberry Pi 3 | Arduino Mega 2560 | 용도 |
|---|---|---|
| USB | USB | Serial 통신 |
| USB | USB | Arduino 로직 전원 공급 |

```text
Raspberry Pi 3
      │
      │ USB
      ▼
Arduino Mega 2560
```

Arduino Mega에는 확장보드를 사용하며, 외부 장치는 확장보드를 통해 연결한다.

프로그램에서 사용하는 핀 번호는 Arduino Mega의 Digital Pin 번호를 기준으로 한다.

---

# 4. HC-SR04 Pinout

HC-SR04 초음파 센서는 Arduino Mega 2560에 연결한다.

| HC-SR04 | Arduino Mega | 역할 |
|---|---:|---|
| VCC | 5V | 센서 전원 |
| GND | GND | Ground |
| TRIG | D7 | Trigger |
| ECHO | D8 | Echo |

```text
Arduino Mega
│
├── 5V  → HC-SR04 VCC
├── GND → HC-SR04 GND
├── D7  → HC-SR04 TRIG
└── D8  → HC-SR04 ECHO
```

---

# 5. Linear Motor PWM Pinout

| Arduino Mega | L298N | Channel | Motor | Role |
|---:|---|---|---|---|
| D2 | L298N #3 | ENB | Motor 2 | PWM |
| D3 | L298N #1 | ENB | Motor 1 | PWM |
| D4 | L298N #2 | ENA | Motor 3 | PWM |
| D5 | L298N #2 | ENB | Motor 4 | PWM |
| D6 | L298N #3 | ENA | Motor 5 | PWM |

### PWM 핀 요약

```text
D2 → L298N #3 ENB → Motor 2
D3 → L298N #1 ENB → Motor 1
D4 → L298N #2 ENA → Motor 3
D5 → L298N #2 ENB → Motor 4
D6 → L298N #3 ENA → Motor 5
```

---

# 6. Linear Motor Direction Control Pinout

## 6-1. L298N #1

L298N #1은 Motor 1을 제어한다.

Motor 1은 B Channel을 사용한다.

| Arduino Mega | L298N #1 | Motor |
|---:|---|---|
| D22 | IN3 | Motor 1 |
| D23 | IN4 | Motor 1 |
| D3 | ENB | Motor 1 PWM |

```text
Arduino D22 → IN3
Arduino D23 → IN4
Arduino D3  → ENB

OUT3 / OUT4
      │
      ▼
Linear Motor 1
```

L298N #1의 A Channel은 사용하지 않는다.

---

## 6-2. L298N #2

L298N #2는 Motor 3과 Motor 4를 제어한다.

### A Channel — Motor 3

| Arduino Mega | L298N #2 | Motor |
|---:|---|---|
| D24 | IN1 | Motor 3 |
| D25 | IN2 | Motor 3 |
| D4 | ENA | Motor 3 PWM |

```text
Arduino D24 → IN1
Arduino D25 → IN2
Arduino D4  → ENA

OUT1 / OUT2
      │
      ▼
Linear Motor 3
```

### B Channel — Motor 4

| Arduino Mega | L298N #2 | Motor |
|---:|---|---|
| D26 | IN3 | Motor 4 |
| D27 | IN4 | Motor 4 |
| D5 | ENB | Motor 4 PWM |

```text
Arduino D26 → IN3
Arduino D27 → IN4
Arduino D5  → ENB

OUT3 / OUT4
      │
      ▼
Linear Motor 4
```

---

## 6-3. L298N #3

L298N #3은 Motor 5와 Motor 2를 제어한다.

### A Channel — Motor 5

| Arduino Mega | L298N #3 | Motor |
|---:|---|---|
| D28 | IN1 | Motor 5 |
| D29 | IN2 | Motor 5 |
| D6 | ENA | Motor 5 PWM |

```text
Arduino D28 → IN1
Arduino D29 → IN2
Arduino D6  → ENA

OUT1 / OUT2
      │
      ▼
Linear Motor 5
```

### B Channel — Motor 2

| Arduino Mega | L298N #3 | Motor |
|---:|---|---|
| D30 | IN3 | Motor 2 |
| D31 | IN4 | Motor 2 |
| D2 | ENB | Motor 2 PWM |

```text
Arduino D30 → IN3
Arduino D31 → IN4
Arduino D2  → ENB

OUT3 / OUT4
      │
      ▼
Linear Motor 2
```

---

# 7. Arduino Mega 전체 Digital Pin 사용 현황

| Arduino Pin | 연결 대상 | 역할 |
|---:|---|---|
| D2 | L298N #3 ENB | Motor 2 PWM |
| D3 | L298N #1 ENB | Motor 1 PWM |
| D4 | L298N #2 ENA | Motor 3 PWM |
| D5 | L298N #2 ENB | Motor 4 PWM |
| D6 | L298N #3 ENA | Motor 5 PWM |
| D7 | HC-SR04 TRIG | 초음파 Trigger |
| D8 | HC-SR04 ECHO | 초음파 Echo |
| D22 | L298N #1 IN3 | Motor 1 방향 |
| D23 | L298N #1 IN4 | Motor 1 방향 |
| D24 | L298N #2 IN1 | Motor 3 방향 |
| D25 | L298N #2 IN2 | Motor 3 방향 |
| D26 | L298N #2 IN3 | Motor 4 방향 |
| D27 | L298N #2 IN4 | Motor 4 방향 |
| D28 | L298N #3 IN1 | Motor 5 방향 |
| D29 | L298N #3 IN2 | Motor 5 방향 |
| D30 | L298N #3 IN3 | Motor 2 방향 |
| D31 | L298N #3 IN4 | Motor 2 방향 |

---

# 8. Motor별 최종 Pinout

| Motor | Driver | Channel | PWM | Direction | Output |
|---|---|---|---:|---|---|
| Motor 1 | L298N #1 | B | D3 | D22 / D23 | OUT3 / OUT4 |
| Motor 2 | L298N #3 | B | D2 | D30 / D31 | OUT3 / OUT4 |
| Motor 3 | L298N #2 | A | D4 | D24 / D25 | OUT1 / OUT2 |
| Motor 4 | L298N #2 | B | D5 | D26 / D27 | OUT3 / OUT4 |
| Motor 5 | L298N #3 | A | D6 | D28 / D29 | OUT1 / OUT2 |

---

# 9. L298N별 최종 Pinout

## L298N #1

```text
Motor 1

Arduino D3  → ENB
Arduino D22 → IN3
Arduino D23 → IN4

OUT3 / OUT4 → Motor 1
```

---

## L298N #2

```text
Motor 3

Arduino D4  → ENA
Arduino D24 → IN1
Arduino D25 → IN2

OUT1 / OUT2 → Motor 3

Motor 4

Arduino D5  → ENB
Arduino D26 → IN3
Arduino D27 → IN4

OUT3 / OUT4 → Motor 4
```

---

## L298N #3

```text
Motor 5

Arduino D6  → ENA
Arduino D28 → IN1
Arduino D29 → IN2

OUT1 / OUT2 → Motor 5

Motor 2

Arduino D2  → ENB
Arduino D30 → IN3
Arduino D31 → IN4

OUT3 / OUT4 → Motor 2
```

---

# 10. U2D2 / DYNAMIXEL 연결

Raspberry Pi 3와 DYNAMIXEL은 U2D2를 통해 통신한다.

```text
Raspberry Pi 3
      │
      │ USB
      ▼
    U2D2
      │
      │ 3핀
      ▼
U2D2 Power Hub
      │
      ├── 3핀 → DYNAMIXEL XL430-W250-T #1
      │
      └── 3핀 → DYNAMIXEL XL430-W250-T #2
```

| 시작 장치 | 연결 대상 | 연결 방식 |
|---|---|---|
| Raspberry Pi 3 | U2D2 | USB |
| U2D2 | U2D2 Power Hub | 3핀 |
| U2D2 Power Hub | DYNAMIXEL #1 | 3핀 |
| U2D2 Power Hub | DYNAMIXEL #2 | 3핀 |

U2D2 Power Hub에는 DYNAMIXEL 구동을 위한 별도 외부 전원을 사용한다.

> 외부 전원의 상세 공급 구조는 `02_Power_Distribution_SMPS.md`에서 관리한다.

---

# 11. Raspberry Pi 전체 GPIO 사용 현황

| BCM GPIO | Physical Pin | 연결 대상 | 역할 |
|---:|---:|---|---|
| GPIO 2 | 3 | I2C LCD SDA | I2C Data |
| GPIO 3 | 5 | I2C LCD SCL | I2C Clock |
| GPIO 5 | 29 | Keypad COL1 | Keypad |
| GPIO 6 | 31 | Keypad COL2 | Keypad |
| GPIO 13 | 33 | Keypad COL3 | Keypad |
| GPIO 19 | 35 | Keypad COL4 | Keypad |
| GPIO 26 | 37 | Keypad ROW1 | Keypad |
| GPIO 12 | 32 | Keypad ROW2 | Keypad |
| GPIO 16 | 36 | Keypad ROW3 | Keypad |
| GPIO 20 | 38 | Keypad ROW4 | Keypad |

---

# 12. 전체 Pinout 요약

```text
Raspberry Pi 3
│
├── GPIO 2  → LCD SDA
├── GPIO 3  → LCD SCL
│
├── GPIO 5  → Keypad COL1
├── GPIO 6  → Keypad COL2
├── GPIO 13 → Keypad COL3
├── GPIO 19 → Keypad COL4
├── GPIO 26 → Keypad ROW1
├── GPIO 12 → Keypad ROW2
├── GPIO 16 → Keypad ROW3
├── GPIO 20 → Keypad ROW4
│
├── USB → Arduino Mega 2560
│
└── USB → U2D2

Arduino Mega 2560
│
├── D2 → Motor 2 PWM
├── D3 → Motor 1 PWM
├── D4 → Motor 3 PWM
├── D5 → Motor 4 PWM
├── D6 → Motor 5 PWM
│
├── D7 → HC-SR04 TRIG
├── D8 → HC-SR04 ECHO
│
├── D22 / D23 → Motor 1 방향
├── D24 / D25 → Motor 3 방향
├── D26 / D27 → Motor 4 방향
├── D28 / D29 → Motor 5 방향
└── D30 / D31 → Motor 2 방향
```

---

# 13. 문서 관리 기준

```text
electric/
├── 01_Wiring_Diagram.md
├── 02_Power_Distribution_SMPS.md
└── 03_Pinout_Table.md
```

## `01_Wiring_Diagram.md`

장치 간 실제 물리적 연결 구조를 관리한다.

- Breadboard
- Arduino 확장보드
- Raspberry Pi ↔ Arduino
- Arduino ↔ HC-SR04
- Arduino ↔ L298N
- L298N ↔ Linear Motor
- Raspberry Pi ↔ U2D2
- U2D2 ↔ Power Hub ↔ DYNAMIXEL

## `02_Power_Distribution_SMPS.md`

전원의 공급 및 분배 구조를 관리한다.

- Raspberry Pi 전원
- Arduino 전원
- 12V SMPS
- L298N / Linear Motor 전원
- U2D2 Power Hub 외부 전원
- DYNAMIXEL 구동 전원

## `03_Pinout_Table.md`

실제 제어 핀 번호를 관리한다.

- Raspberry Pi GPIO
- LCD SDA / SCL
- Keypad ROW / COL
- Arduino Digital Pin
- HC-SR04 TRIG / ECHO
- L298N ENA / ENB
- L298N IN1 ~ IN4
- Motor별 제어 핀

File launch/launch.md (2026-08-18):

# ROS 2 시스템 전체 실행

## 1. 개요

본 프로젝트의 ROS 2 시스템 전체를 한 번에 실행하기 위한 Launch 파일이다.

Launch 파일을 실행하면 스마트 시트 시스템에 필요한 5개의 ROS 2 노드가 동시에 실행된다.

### 실행되는 노드

| 노드 이름 | 실행 파일 | 주요 역할 |
| --- | --- | --- |
| `arduino_bridge_node` | `arduino_bridge_node.py` | Raspberry Pi와 Arduino 간 통신 및 모터 명령 전달 |
| `profile_inference_node` | `profile_inference_node.py` | 사용자 데이터를 기반으로 좌석 프로파일 추론 |
| `seat_controller_node` | `seat_controller_node.py` | 목표 좌석 프로파일에 따른 좌석 제어 |
| `keypad_node` | `keypad_node.py` | 키패드 입력 및 사용자 프로필 제어 |
| `belt_controller_node` | `belt_controller_node.py` | 안전벨트 제어 |

---

## 2. 시스템 구성

Launch 파일은 다음과 같은 구조로 ROS 2 노드를 실행한다.

```text
                    ┌─────────────────────────┐
                    │       keypad_node        │
                    │     키패드 입력 처리      │
                    └────────────┬────────────┘
                                 │
                                 ▼
                    ┌─────────────────────────┐
                    │ profile_inference_node  │
                    │   사용자 프로파일 추론   │
                    └────────────┬────────────┘
                                 │
                                 ▼
                    ┌─────────────────────────┐
                    │  seat_controller_node   │
                    │      좌석 제어 처리       │
                    └────────────┬────────────┘
                                 │
                                 ▼
                    ┌─────────────────────────┐
                    │  arduino_bridge_node    │
                    │   Arduino 통신 / 모터제어 │
                    └────────────┬────────────┘
                                 │
                                 ▼
                         ┌──────────────┐
                         │   Arduino    │
                         │ 모터 드라이버 │
                         └──────────────┘

                    ┌─────────────────────────┐
                    │  belt_controller_node   │
                    │       안전벨트 제어       │
                    └─────────────────────────┘
```

> 실제 ROS 2 통신 구조는 각 노드의 Publisher / Subscriber 설정에 따라 달라질 수 있으며, 위 구조는 Launch 파일에서 실행되는 주요 노드의 역할을 나타낸다.

---

## 3. 실행 전 준비

### 3.1 ROS 2 환경 설정

터미널에서 ROS 2 Humble 환경을 불러온다.

```bash
source /opt/ros/humble/setup.bash
```

### 3.2 ROS 2 Workspace 설정

프로젝트의 Workspace를 빌드한 후 환경을 불러온다.

```bash
cd ~/ros2_ws
colcon build
source install/setup.bash
```

매번 `source` 명령을 입력하기 어려운 경우 `~/.bashrc`에 등록할 수 있다.

```bash
source ~/ros2_ws/install/setup.bash
```

---

## 4. Arduino 연결 확인

Arduino를 Raspberry Pi에 연결한 후 장치가 정상적으로 인식되는지 확인한다.

```bash
ls /dev/ttyUSB*
```

Arduino가 정상적으로 연결되어 있다면 다음과 같이 표시될 수 있다.

```text
/dev/ttyUSB0
```

Arduino Bridge Node에서 사용하는 포트와 실제 연결된 포트가 동일한지 확인한다.

---

## 5. 시스템 전체 실행

ROS 2 환경과 Workspace를 설정한 후 Launch 파일을 실행한다.

```bash
source /opt/ros/humble/setup.bash
source ~/ros2_ws/install/setup.bash
```

이후 다음 명령어를 실행한다.

```bash
ros2 launch smart_seat [launch파일명].py
```

예를 들어 Launch 파일 이름이 `smart_seat.launch.py`라면:

```bash
ros2 launch smart_seat smart_seat.launch.py
```

Launch 파일을 실행하면 다음 5개의 노드가 동시에 실행된다.

```text
arduino_bridge_node
profile_inference_node
seat_controller_node
keypad_node
belt_controller_node
```

---

## 6. 실행 확인

새로운 터미널을 열고 ROS 2 환경을 다시 설정한다.

```bash
source /opt/ros/humble/setup.bash
source ~/ros2_ws/install/setup.bash
```

### 실행 중인 노드 확인

```bash
ros2 node list
```

정상적으로 실행되었다면 다음 노드들이 표시되어야 한다.

```text
/arduino_bridge_node
/profile_inference_node
/seat_controller_node
/keypad_node
/belt_controller_node
```

### ROS 2 Topic 확인

```bash
ros2 topic list
```

현재 실행 중인 노드들이 사용하는 Topic이 정상적으로 생성되었는지 확인한다.

### 특정 Topic의 연결 상태 확인

예:

```bash
ros2 topic info /motor_cmd
```

Publisher와 Subscriber가 정상적으로 연결되어 있는지 확인한다.

---

## 7. Arduino Bridge Node 확인

Arduino와 Raspberry Pi의 통신이 정상적으로 연결되었는지 Launch 터미널의 로그를 확인한다.

정상적으로 연결되면 다음과 같은 형태의 메시지가 출력된다.

```text
아두이노 연결 성공: /dev/ttyUSB0 @ 115200
```

또한 모터 명령이 전달될 경우 다음과 같은 로그가 출력될 수 있다.

```text
모터 명령 전송: M,1,1,200
```

---

## 8. 시스템 종료

Launch로 실행된 전체 시스템을 종료하려면 Launch가 실행 중인 터미널에서 다음을 입력한다.

```text
Ctrl + C
```

Launch 파일에서 실행한 모든 ROS 2 노드가 함께 종료된다.

---

## 9. 문제 발생 시 확인

### 노드가 실행되지 않는 경우

```bash
ros2 node list
```

를 사용하여 필요한 노드가 실행되고 있는지 확인한다.

### Arduino가 인식되지 않는 경우

```bash
ls /dev/ttyUSB*
```

를 실행하여 Arduino 장치가 존재하는지 확인한다.

### `/motor_cmd` 연결 확인

```bash
ros2 topic info /motor_cmd
```

`Subscription count`가 0인 경우 모터 명령을 받을 Subscriber가 실행되지 않은 상태일 수 있으므로 `arduino_bridge_node`가 정상적으로 실행되었는지 확인한다.

### 패키지를 찾을 수 없는 경우

```text
Package 'smart_seat' not found
```

와 같은 오류가 발생하면 다음 명령어를 실행한다.

```bash
source /opt/ros/humble/setup.bash
source ~/ros2_ws/install/setup.bash
```

필요한 경우 Workspace를 다시 빌드한다.

```bash
cd ~/ros2_ws
colcon build
source install/setup.bash
```

---

## 10. Launch 파일 구성

현재 Launch 파일에서는 ROS 2 콘솔 출력 형식을 설정한 후 5개의 노드를 실행한다.

```python
from launch import LaunchDescription
from launch_ros.actions import Node
from launch.actions import SetEnvironmentVariable

def generate_launch_description():
    return LaunchDescription([
        SetEnvironmentVariable(
            'RCUTILS_COLORIZED_OUTPUT',
            '1'
        ),

        SetEnvironmentVariable(
            'RCUTILS_CONSOLE_OUTPUT_FORMAT',
            '[{name}] {message}'
        ),

        Node(
            package='smart_seat',
            executable='arduino_bridge_node.py',
            name='arduino_bridge_node',
            output='screen',
        ),

        Node(
            package='smart_seat',
            executable='profile_inference_node.py',
            name='profile_inference_node',
            output='screen',
        ),

        Node(
            package='smart_seat',
            executable='seat_controller_node.py',
            name='seat_controller_node',
            output='screen',
        ),

        Node(
            package='smart_seat',
            executable='keypad_node.py',
            name='keypad_node',
            output='screen',
        ),

        Node(
            package='smart_seat',
            executable='belt_controller_node.py',
            name='belt_controller_node',
            output='screen',
        ),
    ])
```

---

## 11. 전체 실행 순서

```text
① Raspberry Pi 전원 ON
        ↓
② Arduino 연결
        ↓
③ ROS 2 Humble 환경 설정
        ↓
④ smart_seat Workspace 환경 설정
        ↓
⑤ Arduino 연결 상태 확인
        ↓
⑥ Launch 파일 실행
        ↓
⑦ 5개 ROS 2 Node 실행
        ↓
⑧ Node / Topic 연결 상태 확인
        ↓
⑨ 스마트 시트 시스템 동작
```

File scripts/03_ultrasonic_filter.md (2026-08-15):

# Ultrasonic Filter

`keypad_node.py` 안의 HC-SR04 거리 측정 및 노이즈 방어 로직입니다.

## 측정 원리

```python
def _read_ultrasonic_distance_mm(self):
    # TRIG 10us 펄스 발생
    # ECHO 신호 상승/하강 시각 측정
    # duration × 음속(34300mm/s) / 2 = 거리(mm)
```

## 노이즈 방어 로직 (현재 구현)

### 1. ECHO 타임아웃 가드

ECHO 핀이 0→1, 1→0으로 전이하는 두 구간 각각에 **50ms 타임아웃**을 두어, 신호가 안 잡히거나 계속 붙잡혀 있는 경우 `None`을 반환하고 측정을 포기합니다.

> 이 가드가 없던 초기 버전에서는 8590mm 같은 물리적으로 불가능한 값이나 "ECHO 종료 안 됨"으로 무한 대기하는 문제가 있었습니다. 센서를 신뢰도 높은 것으로 교체하면서 실측값(500~600mm대)이 나오기 시작했지만, 방어 로직 자체는 유지합니다.

### 2. 음수/범위 가드

```python
model_sitting_height = SENSOR_HEIGHT_ABOVE_CUSHION_MM - distance_mm
if model_sitting_height <= 0:
    # 센서 아래에 유효한 대상이 없다고 판단, "Sensor Error" 표시 후 중단
```

센서 설치 높이(570mm)보다 먼 거리가 측정되면(즉 센서 아래 유효 범위 밖), 계산을 진행하지 않고 에러로 처리합니다.

### 3. 최종 키 추정값 범위 검증

계산된 추정 키가 130~185cm 설계 범위를 벗어나면 `/body_data`를 발행하지 않고 `Applicable Range 130~185cm`만 표시합니다(자세한 계산 흐름은 `Seat_Control_Algorithm.md` 4절 참고).

## ⚠️ 현재 구현의 한계 — 단일 측정(Single-shot)

현재는 **측정을 1회만 수행**하고 바로 계산에 사용합니다. 이동평균이나 중앙값 필터 같은 다중 샘플 노이즈 제거는 아직 적용되어 있지 않습니다. 초음파 센서 특성상 옷차림(특히 머리카락, 후드 등)에 반사가 불안정할 수 있어, 다음과 같은 개선 여지가 있습니다:

- **개선안**: 짧은 간격으로 3~5회 측정 후 중앙값(median) 사용 → 이상치(outlier) 하나에 흔들리지 않도록
- 우선순위: 현재 단일 측정으로도 검증된 정확도를 보이고 있어(시연 거리표 기준 오차 범위 내), 필수는 아니지만 향후 안정성 개선 항목으로 고려할 수 있습니다.

## 관련 상수

```python
SENSOR_HEIGHT_ABOVE_CUSHION_MM = 570.0   # 방석 기준 센서 설치 높이(모형)
```

키패드 배선 노이즈(유령 신호) 방지 로직은 이 초음파 측정과는 별개로, `scan_keypad()`의 디바운스/다중키 필터에서 처리합니다 — 자세한 내용은 `guest_mode.md`와 `Ros_Architecture.md`를 참고하세요.

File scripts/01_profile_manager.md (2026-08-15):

# Profile Manager

`keypad_node.py` 안의 가족 프로필 로딩/관리 로직입니다.

## 저장 위치

```
~/ros2_ws/src/smart_seat/profiles.json
```

## 데이터 구조

```json
{
  "A": {"name": "PAPA",     "height": 178, "pregnant": false},
  "B": {"name": "MAMA",     "height": 162, "pregnant": true},
  "C": {"name": "DAUGHTER", "height": 130, "pregnant": false}
}
```

| 필드 | 타입 | 설명 |
|---|---|---|
| `name` | string | LCD에 표시될 이름 |
| `height` | number | 신장(cm) |
| `pregnant` | boolean | 임산부 모드 여부 — `true`면 요추 곡선/벨트 목표가 임산부용 계산식으로 전환 |

## 로딩 동작

- 노드 시작 시 `load_profiles()`가 파일을 읽어 딕셔너리로 로드
- **파일이 없거나 파싱 실패 시**: 하드코딩된 기본값(A=PAPA 178cm, B=MAMA 162cm 임산부, C=DAUGHTER 130cm)으로 자동 대체하여 최소한의 시연 가능 상태를 보장

## 프로필 키 눌렀을 때 동작

```
A/B/C 중 하나 눌림
  → profiles[key] 조회
  → LCD: "Mode: {name}{(Preg) 표시}" / "Target: {height}cm"
  → send_height(height, pregnant) 호출 → /body_data 발행
```

## 프로필 값 변경 방법

`profiles.json`을 직접 수정하면 됩니다(코드 재빌드 불필요, 노드만 재시작). 팀원 실측 키로 갱신하거나, 시연 대상자에 맞춰 조정할 때 이 파일만 바꾸면 됩니다.

## 딸(C) 프로필 기준 키 관련 참고

초기값은 실측 아동 키(121cm)였으나, 어린이 인체치수 데이터 부재로 Size Korea 성인 데이터의 신뢰 구간 하한(130cm)에 맞춰 130cm로 조정했습니다. 시스템 설계 범위(130~185cm) 전체와 일관성을 유지하기 위한 결정입니다.

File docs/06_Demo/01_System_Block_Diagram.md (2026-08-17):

system_block_diagram

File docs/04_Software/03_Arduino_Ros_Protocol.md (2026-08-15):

# Arduino ↔ ROS 2 Serial Protocol

`arduino_bridge_node`(ROS 2)와 Arduino Mega(리니어 액추에이터 제어 펌웨어) 사이의 시리얼 통신 프로토콜 명세입니다.

---

## 1. 연결 정보

| 항목 | 값 |
|---|---|
| 장치 경로 | `/dev/arduino_linear` (udev로 고정) |
| 통신 속도 | 115200 bps |
| 부팅 시 응답 | `READY` |

---

## 2. 명령 프로토콜 (ROS → Arduino)

### 형식

```
M,<모터번호>,<방향>,<속도>\n
```

| 필드 | 범위 | 설명 |
|---|---|---|
| 모터번호 | 1~5 | Arduino 물리 모터 채널 (EN/IN 핀은 [`03_Pinout_Table.md`](../02_Design/electrical/03_Pinout_Table.md) 참고) |
| 방향 | -1, 0, 1 | -1=후진, 0=정지, 1=전진 |
| 속도 | 0~255 | PWM 듀티 (`PWM_SPEED = 200` 고정값 사용) |

### 예시

```
M,1,1,200      # 모터1 전진, 속도 200
M,3,-1,200     # 모터3 후진, 속도 200
M,2,0,0        # 모터2 정지
```

### 채널 ↔ 위치 매핑 (소프트웨어 보정)

Arduino 물리 모터 채널과 등받이 배치 위치(150/320/490/660/830mm)는 조립 과정에서 1·2번이 뒤바뀐 상태로 고정되어, `seat_controller_node`의 `MOTOR_MAP`으로 소프트웨어에서 보정합니다.

```python
MOTOR_MAP = [2, 1, 3, 4, 5]
# 배열 인덱스(0=150mm, 1=320mm, 2=490mm, 3=660mm, 4=830mm)
# → 실제 전송되는 Arduino 물리 모터 번호
```

즉 150mm 위치를 제어하려면 실제로는 `M,2,...`를 전송하고, 320mm 위치는 `M,1,...`을 전송합니다.

---

## 3. 응답 프로토콜 (Arduino → ROS)

```
OK M<모터번호> dir=<방향> spd=<속도>
```

예: `OK M1 dir=1 spd=200`

---

## 4. 리셋 시퀀스

`seat_controller_node`가 리셋 신호(`/target_seat_profile`의 `actuator_mm` 전체 0 이하)를 받으면:

1. 현재 위치(`current_mm`) 기준으로 모터별 필요 후진 시간을 계산 (가장 오래 걸리는 모터 + 여유 3초)
2. 모든 모터에 `M,<번호>,-1,200` 동시 전송
3. 계산된 시간만큼 대기
4. 2번 모터를 제외한 나머지 모터에 정지 명령(`M,<번호>,0,0`) 전송
5. 3초 추가 대기 후 2번 모터에 정지 명령 전송 (조립 특성상 2번 모터가 더 오래 걸림)
6. `current_mm`을 전부 0으로 초기화

> 위치 센서(엔코더)가 없는 시스템이므로, `current_mm`은 마지막으로 전송한 목표값을 소프트웨어에서 추적한 값입니다. 전원이 재시작되면 이 값도 초기화되어 실제 물리 위치와 어긋날 수 있어 재시작 시 리셋 절차가 필요합니다.

---

## 5. 알려진 제약 및 주의사항

- **위치 피드백 없음**: 모든 위치 제어는 "모터별·방향별 실측 속도(mm/s) × 목표 이동거리 = 구동 시간"으로 시간 기반 추정됩니다. 배터리 전압 변화, 기계적 마찰 변화 등에 따라 오차가 누적될 수 있습니다.
- **동시 명령 시 시리얼 지연**: 5개 모터에 순차적으로 명령을 전송하므로, 아주 짧은 시차가 발생합니다 (실사용에 영향 없는 수준).
- **스케치 무결성**: Arduino에 다른 스케치가 올라가 있으면 이 프로토콜 자체가 응답하지 않습니다. `READY` 부팅 메시지 확인으로 검증 가능합니다.

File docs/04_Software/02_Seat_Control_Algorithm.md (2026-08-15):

# Seat Control Algorithm

키(신장) 입력 하나로 등받이 곡선과 안전벨트 높이를 계산하는 알고리즘 전체를 정리한 문서입니다. 실물 대비 2:1 축소 모형이라는 전제 하에, 모든 계산식은 **실물 기준으로 유도한 뒤 마지막에 스케일(0.5)을 적용**하는 구조로 통일했습니다.

---

## 1. 앉은키 회귀식 (Size Korea 8차 인체치수조사)

유효 표본 5,092명 데이터를 선형 회귀 분석하여 도출했습니다.

```
앉은키(mm) = 4.2999 × 키(cm) + 0.2129 × 몸무게(kg) + 171.2187
결정계수 R² = 0.842
```

- 몸무게의 영향력은 키의 약 1/20 수준으로 미미하여, 키패드 프로필/게스트 입력 시 몸무게는 65kg 고정값을 사용합니다.
- 설계 적용 범위: 키 130~185cm (185cm = 한국 성인 남성 99백분위수 기준)

---

## 2. 등받이 곡선 — 가우시안 보간

리니어 액추에이터 5개가 각각 150 / 320 / 490 / 660 / 830mm(실물 기준) 높이에 배치되어 있습니다. 천+솜 구조의 좌석 표면을 5개의 독립된 점이 아니라 **연속된 곡면**으로 근사하기 위해, 각 액추에이터의 밀기량을 가우시안 함수로 계산합니다.

### 2-1. 요추(허리) 곡선

```python
lumbar_apex = 앉은키 × LUMBAR_RATIO
push_lumbar(motor_h) = LUMBAR_MAX_PUSH × exp( -((motor_h - lumbar_apex) / LUMBAR_WIDTH)² )
```

| 파라미터 | 일반 모드 | 임산부 모드 |
|---|---|---|
| `LUMBAR_RATIO` | 0.18 | 0.12 (정점을 낮춤) |
| `LUMBAR_MAX_PUSH` | 95.0mm | 55.0mm (약하게) |
| `LUMBAR_WIDTH` | 200.0mm | 250.0mm (넓게 분산) |

**임산부 모드를 별도로 두는 근거**: 일반적인 강한 요추 지지가 임신 중 요추 전만(lordosis)을 과도하게 만들거나 장골동맥을 압박할 위험이 있다는 인체공학 문헌에 근거하여, 정점을 낮추고 힘을 약하게, 대신 넓게 분산시켰습니다.

### 2-2. 머리 지지(헤드레스트) 곡선

```python
head_support = 앉은키 - HEAD_CG_OFFSET   # HEAD_CG_OFFSET = 90.0mm
push_head(motor_h) = HEAD_MAX_PUSH × exp( -((motor_h - head_support) / HEAD_WIDTH)² )
# HEAD_MAX_PUSH = 40.0mm, HEAD_WIDTH = 150.0mm
```

### 2-3. 최종 밀기량 결정

```python
push(motor_h) = max(push_lumbar(motor_h), push_head(motor_h))
push = min(push, MAX_STROKE_MM)   # 액추에이터 최대 스트로크로 제한
scaled_push = push × SCALE        # SCALE = 0.5 (2:1 축소 모형 반영)
```

하나의 물리 모터가 사용자 키에 따라 요추 지지 역할과 머리 지지 역할을 겸합니다. 예: 키가 작으면 상단 모터가 요추보다 머리 지지 값이 더 커져 자동으로 헤드레스트 역할로 전환됩니다.

---

## 3. 안전벨트 높이 계산

### 3-1. 목표 높이 (실물 기준)

| 모드 | 계산식 | 근거 |
|---|---|---|
| 일반 | `앉은키 × 0.80` (어깨 중앙) | 자동차 안전 매뉴얼 공통 기준: 벨트는 어깨 중앙을 지나야 함(목이면 위험, 팔 아래면 이탈 위험) |
| 임산부 | 고정값 125.0mm (골반) | 100~150mm 범위의 중간값, 복부 압박 방지 |

> "성인 평균 체형(AM50: 175cm·78kg)" 기준 설계의 한계를 데이터로 보정한다는 것이 이 프로젝트의 핵심 차별점입니다. AM50과 대비되는 5th percentile 여성 더미(152cm·50kg)는 최근에야 일부 도입되기 시작했다는 점도 이 설계 방향의 근거입니다.

### 3-2. 좌표계 — 방석 표면을 원점(0mm)으로 통일

```
바닥(0mm) → 방석 표면(75mm, 기준 원점) → 벨트 홈 포지션(실측) → 목표 높이
```

모든 벨트 관련 계산은 "방석 표면 = 0mm" 기준 하나로 통일하여 계산 오차를 방지합니다.

### 3-3. 모형 변환 및 틱 변환

```python
target_model_mm = target_real_mm × SCALE + BELT_CALIBRATION_OFFSET_MM
# SCALE = 0.5
# BELT_CALIBRATION_OFFSET_MM = 25.0  (실측 보정값, 아래 3-4 참고)

필요틱수 = (target_model_mm - BELT_HOME_ABOVE_CUSHION) × BELT_TICKS_PER_MM
# BELT_HOME_ABOVE_CUSHION = -45.0  (홈이 방석보다 45mm 아래)
# BELT_TICKS_PER_MM = 37.3         (실측 캘리브레이션 값)
```

### 3-4. 실측 캘리브레이션 근거

- 이론값(릴 지름 25mm 기준 원주 계산)이 아니라, 실제로 500mm를 이동시켜 측정한 값(약 18,449틱)으로 틱/mm 비율을 도출했습니다.
- A/B/C 세 프로필로 실측한 결과, 계산값이 실제 도달 높이보다 18~30mm씩 항상 부족하게 나와 평균 **+25mm 보정값**을 추가로 적용했습니다.

---

## 4. 초음파 자동 키 추정 (게스트 모드)

D키 3초 롱프레스 시, 방석 위 570mm(모형 기준)에 설치된 HC-SR04 초음파 센서로 앉은키를 자동 측정합니다.

```python
model_sitting_height = SENSOR_HEIGHT_ABOVE_CUSHION_MM - distance_mm   # 570.0 - 측정거리
real_sitting_height = model_sitting_height × 2.0                       # 모형 → 실물 환산 (2:1의 역)

# 1절의 회귀식을 키(h)에 대해 역산
h = (real_sitting_height - SIT_B × 65.0 - SIT_C) / SIT_A
```

- `130.0 ≤ h ≤ 185.0`이면 즉시 적용, 범위를 벗어나면 LCD에 `Applicable Range 130~185cm` 표시 후 미적용
- 센서 설치 높이(570mm) 산출 근거: 바닥에서 585mm 위치에 고정대, 60mm 브라켓으로 하향 장착 → 총 645mm(바닥 기준) − 75mm(방석 두께) = 570mm(방석 기준)

---

## 5. 핵심 상수 요약

```python
SIT_A, SIT_B, SIT_C = 4.2999, 0.2129, 171.2187   # 앉은키 회귀식
SCALE = 0.5                                       # 2:1 축소 모형

LUMBAR_RATIO, LUMBAR_MAX_PUSH, LUMBAR_WIDTH = 0.18, 95.0, 200.0
PREG_LUMBAR_RATIO, PREG_LUMBAR_MAX_PUSH, PREG_LUMBAR_WIDTH = 0.12, 55.0, 250.0
HEAD_CG_OFFSET, HEAD_MAX_PUSH, HEAD_WIDTH = 90.0, 40.0, 150.0
MOTOR_HEIGHTS = [150.0, 320.0, 490.0, 660.0, 830.0]
MAX_STROKE_MM = 100.0

BELT_SHOULDER_RATIO = 0.80
BELT_PREGNANT_TARGET_REAL = 125.0
BELT_HOME_ABOVE_CUSHION = -45.0
BELT_TICKS_PER_MM = 37.3
BELT_CALIBRATION_OFFSET_MM = 25.0

SENSOR_HEIGHT_ABOVE_CUSHION_MM = 570.0
GUEST_WEIGHT_KG = 65.0
```

## 6. 설계 범위와 한계

- 130~185cm 범위 밖(예: 초음파 자동측정에서 벗어난 경우)은 지원하지 않으며, 안내 메시지만 표시합니다.
- 몸무게를 항상 65kg 고정값으로 사용하므로, 실제 몸무게가 크게 다른 사용자는 앉은키 추정에 소폭 오차가 있을 수 있습니다(회귀식에서 몸무게 계수의 영향력 자체가 작아 오차 폭은 제한적입니다).
- 벨트 캘리브레이션(37.3틱/mm, +25mm 보정)은 현재 모형 개체에 대한 실측값으로, 하드웨어가 바뀌면(릴 교체, 재조립 등) 재실측이 필요합니다.

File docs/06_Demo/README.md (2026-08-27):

# Demo

시연 관련 자료입니다.

## 01_System_Block_Diagram
전기적 배선(결선도, `02_Design/electrical/` 참고)과는 별개로, **기능 단위로 시스템이 어떻게 동작하는지** 보여주는 상위 개념도입니다. 입력 → 체형 데이터 계산 → 등받이/벨트 구동 → 결과의 흐름을 담고 있습니다.

## 02_Hardware_Photos
완성된 시트의 실물 사진입니다. (Fusion 렌더링/도면은 `02_Design/mechanical/3D_model/screenshot/`에 별도로 있습니다.)

## 03_Operation_Videos
프로필 선택(A/B/C), 게스트 모드, 초음파 자동측정, 리셋 등 실제 동작 시연 영상입니다.

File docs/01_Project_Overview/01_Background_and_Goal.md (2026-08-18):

# 개발 배경 및 목표

## 1. 기획 배경

자동차 시트는 대부분 성인 평균 체형 기준으로 고정 설계된다. 자동차 업계에서는 시트 설계 시 미국 성인 남성 50번째 백분위(AM50, 175cm·78kg 표준 더미) 모델을 하중 조건으로 삼는 것이 일반적이다.

그러나 실제 차량에는 카시트를 졸업한 아이, 임산부, 손님 등 체형이 전혀 다른 여러 사람이 번갈아 탑승한다. 체형에 맞지 않는 시트는 잘못된 착석 자세를 유발하고, 특히 안전벨트가 몸에 맞지 않는 위치를 지나가면 충돌 시 부상 위험이 커진다. 미국 교통안전공단의 2011년 조사에 따르면, 동일한 사고 조건에서도 여성 운전자의 부상 확률이 남성보다 47% 높게 나타났는데, 이는 안전장치가 표준체형(남성) 기준으로 설계된 것이 한 원인으로 지목된다.

## 2. 핵심 타겟

- 가족형 RV/SUV 차량 사용자 (다자녀·다세대 가족)
- 임산부
- 단기 카셰어링/렌트 게스트

## 3. 개발 목표

Size Korea 8차 인체치수조사 데이터(유효표본 5,092명)를 기반으로 개인별 요추·어깨 위치를 계산하고, 이를 리니어 액추에이터와 다이나믹셀 서보모터로 실시간 구현하여 **"누가 타든 안전한 자세"를 자동으로 완성**하는 것을 목표로 한다.

- 안전성 개선: 표준체형 기준 설계의 사각지대(여성, 아동, 임산부, 다양한 체형)를 데이터 기반 개인화로 완화
- 편의성 개선: 가족 구성원이 시트 하나를 공유하며, 매번 수동으로 재조정하지 않고 프로필 버튼 하나로 즉시 전환

## 4. 핵심 사용 시나리오

### 시나리오 1 — 가족 모드
저장된 가족 프로필(A/B/C, 이름·키·임산부여부)을 키패드에서 선택하면 즉시 해당 체형에 맞춰 등받이 곡선과 안전벨트 높이가 변형된다.

### 시나리오 2 — 게스트 모드
가족 구성원이 아닌 손님이 탑승할 경우, 두 가지 방법으로 대응한다:
- **수동 입력**: 키패드로 키(cm)를 직접 입력
- **자동 측정**: 천장(헤드레스트 자리)에 장착된 초음파 센서로 3초 롱프레스 시 자동으로 신장을 추정하여 적용

### 시나리오 3 — 임산부 모드
일반 모드와 달리, 요추 지지 곡선을 낮고 부드럽게 조정하고(과도한 요추 전만·장골동맥 압박 방지), 안전벨트는 어깨가 아닌 골반 위치를 지나가도록 가이딩하여 복부 압박을 방지한다.

## 5. 설계 적용 범위

키 130~185cm (185cm은 한국 성인 남성 99백분위수 기준). 이 범위를 벗어나는 경우 시스템은 동작을 적용하지 않고 적용 가능 범위를 안내한다.

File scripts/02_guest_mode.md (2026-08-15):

# Guest Mode

`keypad_node.py` 안의 게스트 입력 처리 로직입니다. 가족 프로필(A/B/C)에 없는 손님이 키를 직접 입력해서 시트를 조절할 수 있게 합니다.

## 진입 방식 2가지

| 방식 | 트리거 | 동작 |
|---|---|---|
| 수동 입력 | D 키 짧게 누름 | LCD에 `Guest Mode / Enter H: _` 표시, 숫자 키패드로 직접 입력 |
| 자동 측정 | D 키 3초 이상 롱프레스 | 초음파 센서로 자동 신장 추정 (별도 문서: `ultrasonic_filter.md` 참고) |

## 수동 입력 상태 흐름

```
D(짧게) → 게스트 모드 진입 (입력 버퍼 초기화)
  ├─ 숫자(0~9) → 버퍼에 추가, LCD 갱신 (최대 6자리)
  ├─ '.'
  │    ├─ 버퍼가 비어있으면 → 게스트 모드 탈출 + 리셋 (허리만)
  │    └─ 버퍼에 값이 있으면 → 소수점 추가 (중복 방지)
  ├─ E → 버퍼 값 파싱 후 범위(130~185cm) 검증
  │    ├─ 범위 내 → 적용(/body_data 발행) 후 게스트 모드 자동 종료
  │    └─ 범위 밖 / 파싱 실패 → 에러 메시지 표시 후 버퍼만 초기화 (게스트 모드 유지)
  └─ D(짧게) → 게스트 모드 취소, 입력 버퍼 폐기
```

## 안전장치 — 게스트 모드 오진입 자동 복구

키패드 배선 노이즈로 인해 의도치 않게 D가 눌려 게스트 모드로 잘못 진입하는 경우가 있었습니다(연장 케이블 접촉 불량 이슈). 이 상태에서 A/B/C 같은 프로필 키를 누르면 원래는 무시되어 사용자가 갇힌 것처럼 느껴지는 문제가 있었는데, 다음 안전장치로 해결했습니다:

> 게스트 모드 중에 프로필 키(A/B/C)가 눌리면, "노이즈로 잘못 들어왔다"고 판단하여 게스트 모드를 자동으로 취소하고 해당 프로필을 즉시 적용합니다.

이전에 시도했던 "일정 시간(15초) 입력 없으면 자동 종료" 방식은, 사용자가 신중하게 숫자를 입력하는 도중에도 타임아웃될 위험이 있어 폐기하고 위 방식으로 대체했습니다.

## 관련 코드 위치

`keypad_node.py` — `process_key()` 메서드의 `if not self.guest_mode_active: ... else: ...` 분기

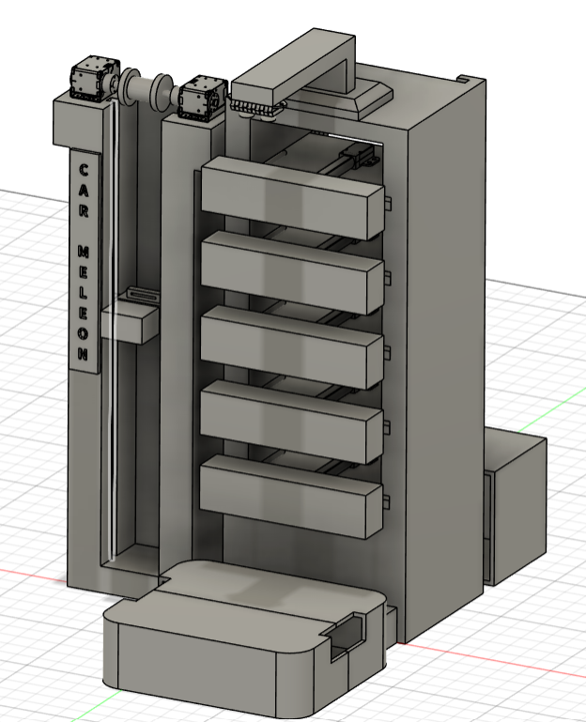
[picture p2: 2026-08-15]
docs/02_Design/mechanical/3D_model/screenshot/design image.png

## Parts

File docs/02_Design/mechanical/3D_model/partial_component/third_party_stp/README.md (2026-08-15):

## 📦 CAD Files & Attributions (출처 및 라이선스)

본 저장소에 포함된 3D CAD 파일(.step)의 출처 및 라이선스 정보입니다.

| 파일명 (File) | 부품명 | 출처 (Source) | 라이선스 / 비고 |
| :--- | :--- | :--- | :--- |
| `XL-430.step` | ROBOTIS DYNAMIXEL XL430-W250 | [ROBOTIS e-Manual](https://docs.robotis.com/docs/dxl/model_reference/x_series/xl_series/xl430-w250#xl430-w250-new) | 제조사 공식 CAD |
| `belt_motor_bracket.step` | XL430 전용 모터 브라켓 | [ROBOTIS e-Manual](https://docs.robotis.com/docs/dxl/model_reference/x_series/xl_series/xl430-w250#xl430-w250-new) | 제조사 공식 CAD |
| `linear_motor.step` | IP60 Linear Actuator | [The Hoodland](https://www.thehoodland.com/ip60-linear-actuator/) | 제조사 공식 CAD |
| `hc-sr04.step` | HC-SR04 Ultrasonic Sensor Module | [Printables](https://www.printables.com/model/1443060-hc-sr04-ultrasonic-sensor-module/files) | **CC BY-NC-SA 4.0** |
| `ultrasonic_sensor_bracket.step` | Hinged Case for HC-SR04 | [MakerWorld](https://makerworld.com/ko/models/1913595-hinged-case-for-ultrasonic-sensor-hc-sr04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) | **Public Domain** |

---

### 💡 저작권 및 사용 조건 (License & Notice)
- **제조사 제공 모델:** `XL-430.step`, `belt_motor_bracket.step`, `linear_motor.step`은 각 제품 제조사의 공식 기술 문서 및 매뉴얼에서 제공하는 CAD 데이터입니다.
- **`hc-sr04.step`:** Printables를 통해 공개된 데이터로, [CC BY-NC-SA 4.0](https://creativecommons.org/licenses/by-nc-sa/4.0/) 라이선스를 따릅니다. (저작자 표시 필요, 비영리 목적 사용, 2차 가공 시 동일 라이선스 적용)
- **`ultrasonic_sensor_bracket.step`:** MakerWorld를 통해 공개된 데이터로, 퍼블릭 도메인(Public Domain) 조건에 따라 자유롭게 사용 가능합니다.

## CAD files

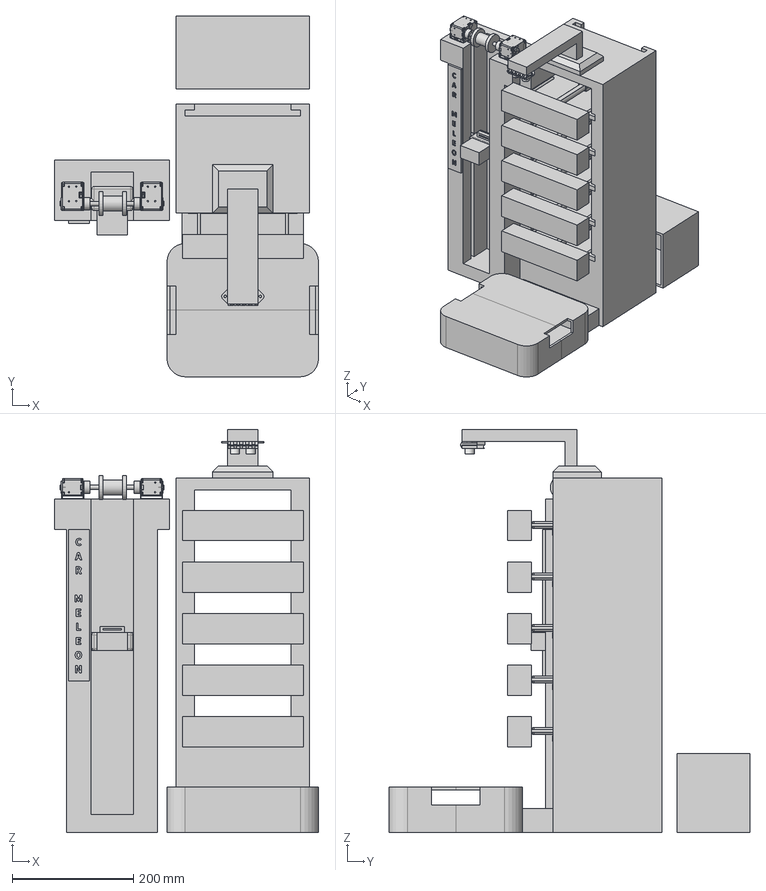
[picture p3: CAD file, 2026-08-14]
docs/02_Design/mechanical/3D_model/assemble/assemble.step
435.7 x 595.1 x 665.0 mm
product0 x 5
µç»ú£¨ÓÒ£© x 5
µç»ú£¨×ó£© x 5
¿ÕÐÄÂÁ¹Ü x 5
Ð¡ÂÁ¿Ç x 5
IP60ÍÆ¸Ë·â¸Ç x 5
ÂÝË¿ x 25
IP60Ïß¿Û x 5
µõ¶ú x 5
hc-sr04

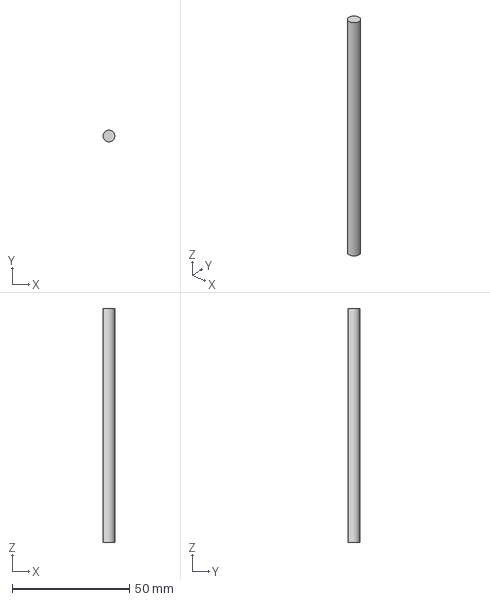
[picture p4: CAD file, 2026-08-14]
docs/02_Design/mechanical/3D_model/partial_component/custom/custom_stp/backrest_shell_drive_pin.step
5.00 x 5.00 x 100.0 mm

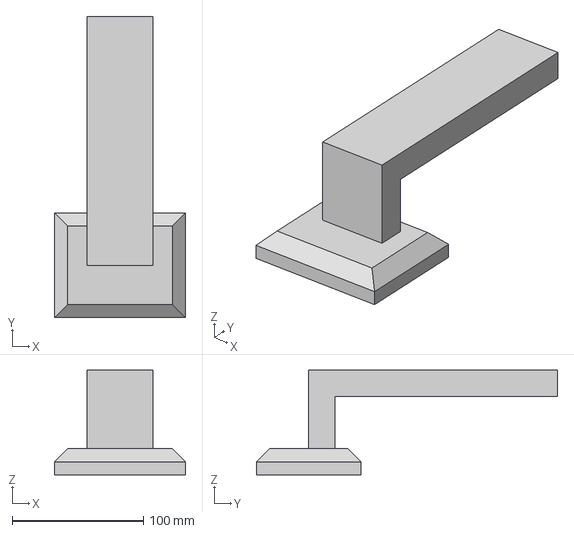
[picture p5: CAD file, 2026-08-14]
docs/02_Design/mechanical/3D_model/partial_component/custom/custom_stp/ultrasonic_sensor_holder_frame.step
100.0 x 230.0 x 80.0 mm

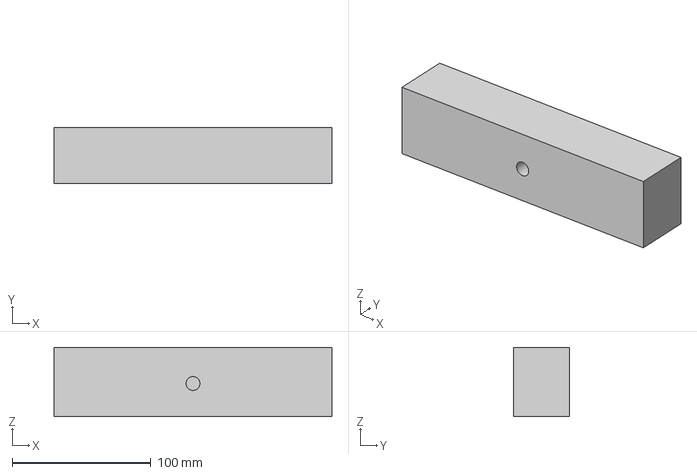
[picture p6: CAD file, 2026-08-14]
docs/02_Design/mechanical/3D_model/partial_component/custom/custom_stp/backrest_shell.step
200.0 x 40.0 x 50.0 mm

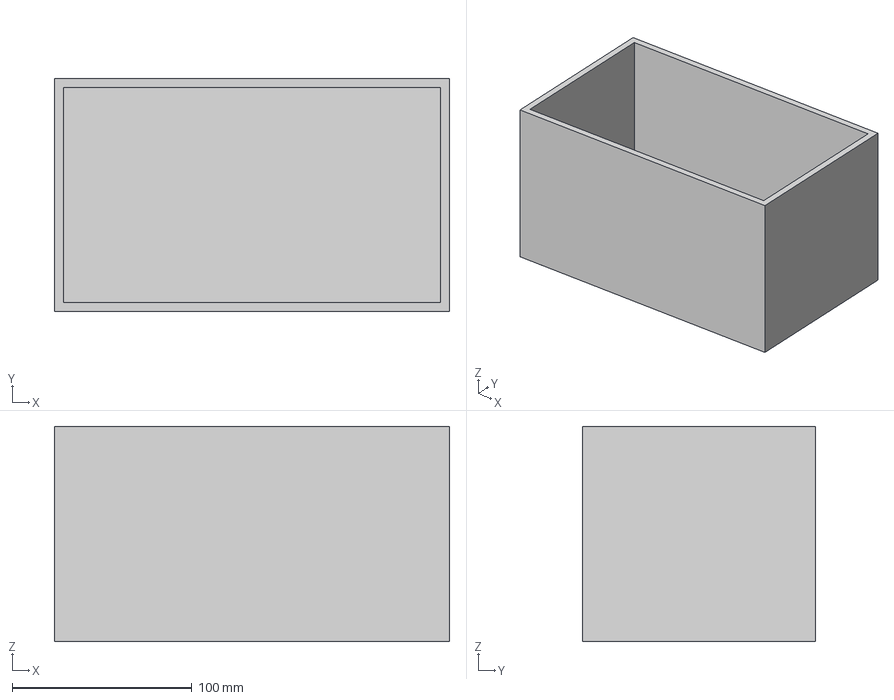
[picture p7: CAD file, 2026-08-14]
docs/02_Design/mechanical/3D_model/partial_component/custom/custom_stp/control_box.step
220.0 x 130.0 x 120.0 mm

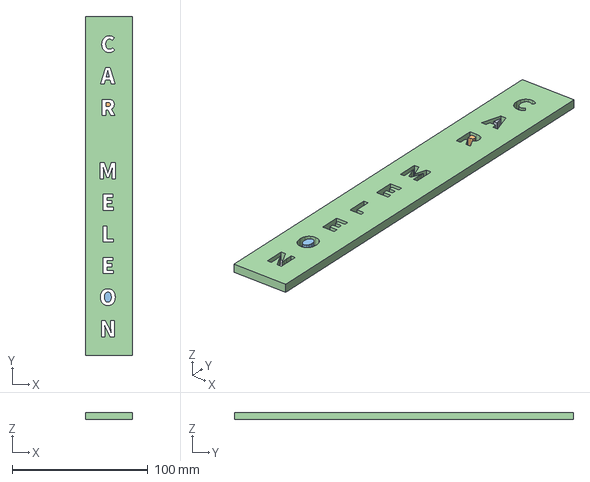
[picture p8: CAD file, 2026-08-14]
docs/02_Design/mechanical/3D_model/partial_component/custom/custom_stp/nameplate.step
35.0 x 250.0 x 5.00 mm

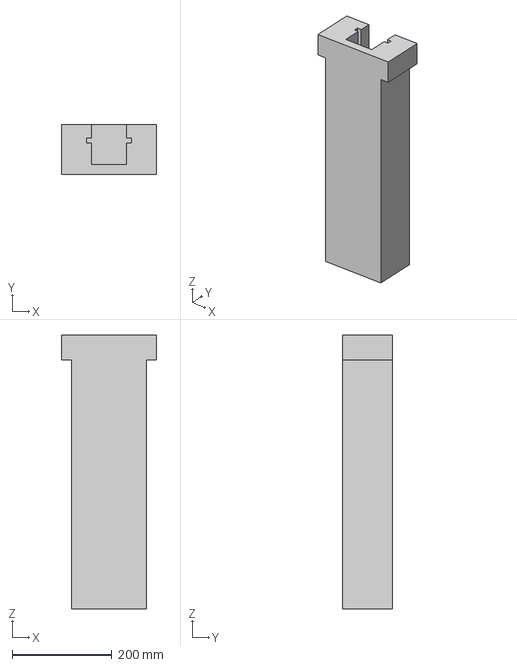
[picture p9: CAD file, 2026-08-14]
docs/02_Design/mechanical/3D_model/partial_component/custom/custom_stp/seatbelt_outer_frame.step
190.0 x 100.0 x 550.0 mm

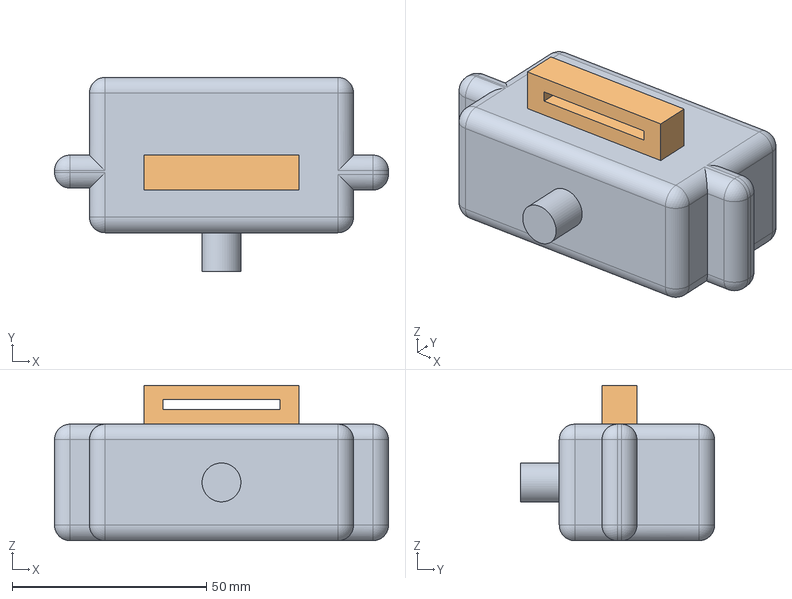
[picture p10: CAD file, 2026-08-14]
docs/02_Design/mechanical/3D_model/partial_component/custom/custom_stp/belt_guide.step
86.0 x 50.0 x 40.0 mm

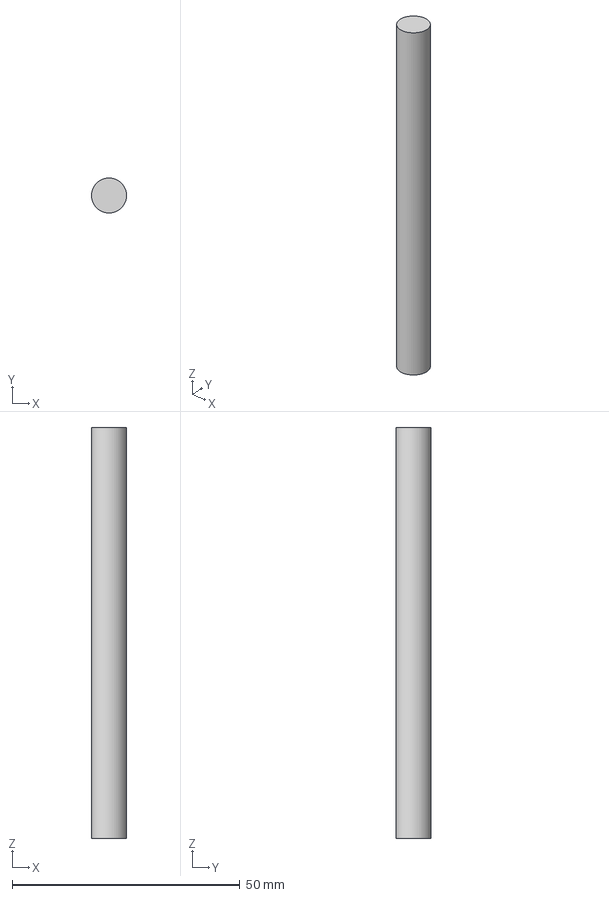
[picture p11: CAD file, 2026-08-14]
docs/02_Design/mechanical/3D_model/partial_component/custom/custom_stp/belt_drive_shaft.step
7.69 x 7.70 x 90.2 mm

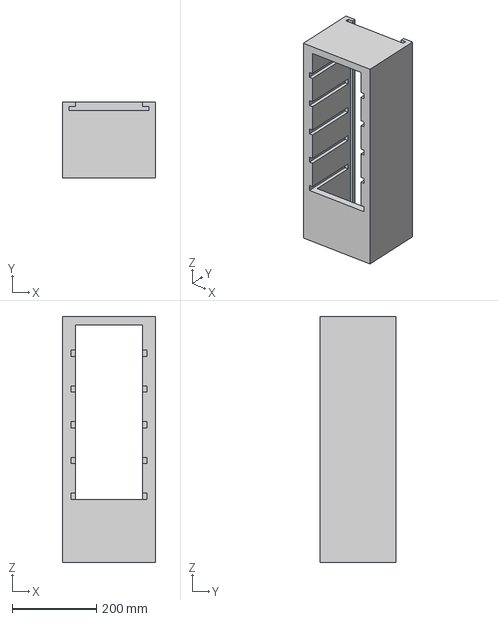
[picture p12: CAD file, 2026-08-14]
docs/02_Design/mechanical/3D_model/partial_component/custom/custom_stp/backrest_outer_frame.step
220.0 x 180.0 x 585.0 mm

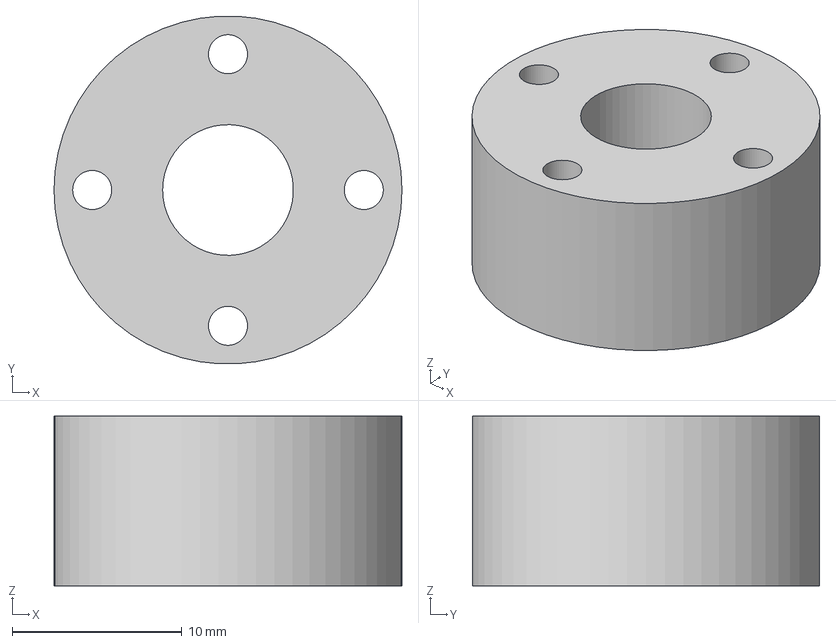
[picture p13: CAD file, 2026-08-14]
docs/02_Design/mechanical/3D_model/partial_component/custom/custom_stp/motor-shaft connecter.step
20.5 x 20.5 x 10.0 mm

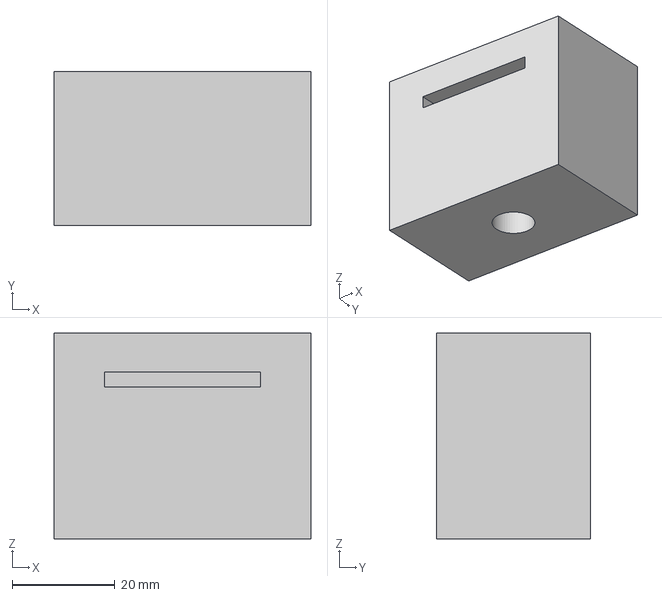
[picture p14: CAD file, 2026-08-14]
docs/02_Design/mechanical/3D_model/partial_component/custom/custom_stp/belt.step
50.0 x 30.0 x 40.0 mm

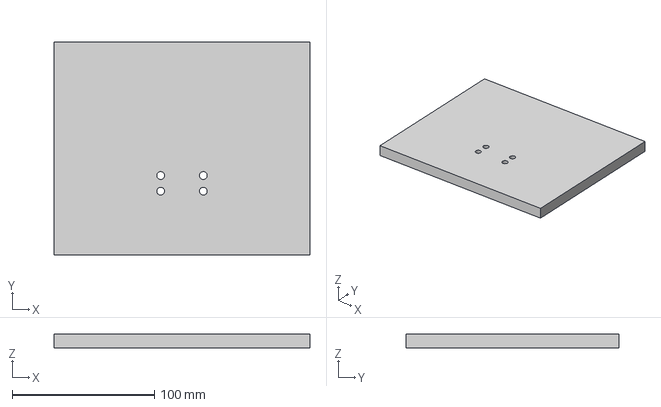
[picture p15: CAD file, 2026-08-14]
docs/02_Design/mechanical/3D_model/partial_component/custom/custom_stp/linear_motor_mount_plate.step
180.0 x 150.0 x 10.0 mm

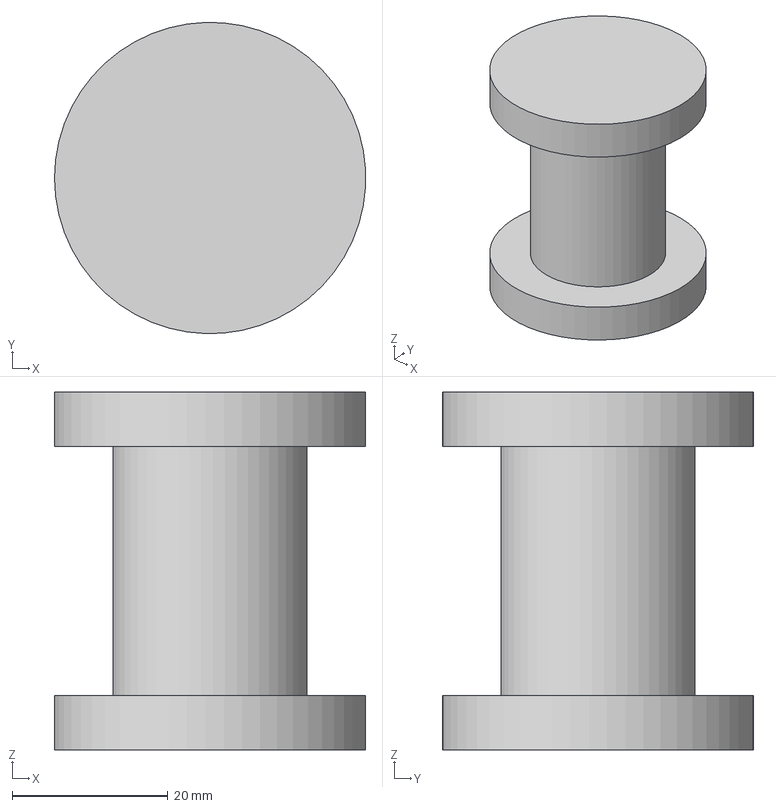
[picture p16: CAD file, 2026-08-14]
docs/02_Design/mechanical/3D_model/partial_component/custom/custom_stp/belt_drive_reel.step
40.0 x 40.0 x 46.0 mm

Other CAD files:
docs/02_Design/mechanical/3D_model/partial_component/custom/custom_stp/seat_bottom.step
docs/02_Design/mechanical/3D_model/assemble/assemble.stl
docs/02_Design/mechanical/3D_model/partial_component/custom/custom_stl/backrest_outer_frame.stl
docs/02_Design/mechanical/3D_model/partial_component/custom/custom_stl/backrest_shell.stl
docs/02_Design/mechanical/3D_model/partial_component/custom/custom_stl/backrest_shell_drive_pin.stl
docs/02_Design/mechanical/3D_model/partial_component/custom/custom_stl/belt.stl
docs/02_Design/mechanical/3D_model/partial_component/custom/custom_stl/belt_drive_reel.stl
docs/02_Design/mechanical/3D_model/partial_component/custom/custom_stl/belt_drive_shaft.stl
docs/02_Design/mechanical/3D_model/partial_component/custom/custom_stl/belt_guide.stl
docs/02_Design/mechanical/3D_model/partial_component/custom/custom_stl/control_box.stl
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

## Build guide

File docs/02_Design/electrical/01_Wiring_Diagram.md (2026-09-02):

# Smart Seat System Wiring Diagram

본 문서는 실제 제작 회로 및 Cirkit Designer에서 작성한 회로도를 기준으로
스마트 시트 시스템의 장치 간 결선 구조를 정리한다.

세부 GPIO 및 Arduino 핀 번호는 `03_Pinout_Table.md`,
전원 공급 및 분배 구조는 `02_Power_Distribution_SMPS.md`에서 관리한다.

---

## 1. Cirkit Designer 전체 회로도
circuit_image
> 전체 시스템의 실제 배선 구성을 Cirkit Designer로 작성한 회로도이다.

---

## 2. 전체 시스템 결선 구조

```mermaid
flowchart TB

    PI["Raspberry Pi 3"]
    BB["Breadboard"]

    LCD["I2C LCD 16×2"]
    KEY["4×4 Matrix Keypad"]

    ARD["Arduino Mega 2560"]
    EXT["Arduino 확장보드"]
    US["HC-SR04"]

    L1["L298N #1"]
    L2["L298N #2"]
    L3["L298N #3"]

    M1["Linear Motor 1"]
    M2["Linear Motor 2"]
    M3["Linear Motor 3"]
    M4["Linear Motor 4"]
    M5["Linear Motor 5"]

    U2["U2D2"]
    HUB["U2D2 Power Hub"]

    DX1["DYNAMIXEL XL430-W250-T #1"]
    DX2["DYNAMIXEL XL430-W250-T #2"]

    PI --> BB
    BB --> LCD
    BB --> KEY

    PI -->|"USB"| ARD
    ARD --> EXT

    EXT --> US

    EXT --> L1
    EXT --> L2
    EXT --> L3

    L1 -->|"OUT3 / OUT4"| M1

    L2 -->|"OUT1 / OUT2"| M3
    L2 -->|"OUT3 / OUT4"| M4

    L3 -->|"OUT1 / OUT2"| M5
    L3 -->|"OUT3 / OUT4"| M2

    PI -->|"USB"| U2
    U2 -->|"3핀 케이블"| HUB

    HUB -->|"3핀 케이블"| DX1
    HUB -->|"3핀 케이블"| DX2
```

---

## 3. Raspberry Pi 3 주변 장치 결선

Raspberry Pi 3는 시스템의 메인 컨트롤러로 사용한다.

I2C LCD와 4×4 Matrix Keypad는 Raspberry Pi GPIO에 연결되며, 실제 회로에서는 Breadboard를 이용하여 배선을 구성한다.

```text
                 Raspberry Pi 3
                       │
                       │ GPIO / 전원
                       ▼
                   Breadboard
                    │      │
                    │      │
                    ▼      ▼
                I2C LCD   4×4 Keypad
```

### 연결 요약

| 시작 장치 | 연결 대상 | 연결 방식 | 역할 |
|---|---|---|---|
| Raspberry Pi 3 | Breadboard | GPIO / 전원 배선 | 주변 장치 연결 |
| Breadboard | I2C LCD 16×2 | I2C / 전원 | 화면 출력 |
| Breadboard | 4×4 Matrix Keypad | GPIO | 사용자 입력 |

> 실제 Raspberry Pi GPIO 번호는 `03_Pinout_Table.md`에서 관리한다.

---

## 4. Raspberry Pi 3 ↔ Arduino Mega 2560

Raspberry Pi 3와 Arduino Mega 2560은 USB 케이블로 연결한다.

```text
Raspberry Pi 3
      │
      │ USB
      ▼
Arduino Mega 2560
```

이 연결을 통해 Raspberry Pi와 Arduino 사이의 Serial 통신을 수행한다.

Arduino Mega는 리니어 모터 제어 및 초음파 센서 처리를 담당한다.

---

## 5. Arduino Mega 2560 ↔ Arduino 확장보드

실제 시스템에서는 Arduino Mega 2560에 확장보드를 사용한다.

```text
Arduino Mega 2560
        │
        ▼
  Arduino 확장보드
```

확장보드는 Arduino의 제어 핀과 외부 장치 간 배선을 편리하게 구성하기 위해 사용한다.

확장보드를 통해 다음 장치가 연결된다.

```text
Arduino 확장보드
        │
        ├──→ HC-SR04
        │
        ├──→ L298N #1
        │
        ├──→ L298N #2
        │
        └──→ L298N #3
```

> 프로그램에서는 Arduino Mega의 기존 Digital Pin 번호를 그대로 사용한다.

---

## 6. HC-SR04 결선

HC-SR04 초음파 센서는 Arduino Mega 2560의 확장보드를 통해 연결한다.

```text
Arduino Mega 2560
        │
        ▼
  Arduino 확장보드
        │
        ▼
     HC-SR04
```

HC-SR04에는 다음 신호 및 전원이 연결된다.

- VCC
- GND
- TRIG
- ECHO

상세 핀 번호는 `03_Pinout_Table.md`에서 관리한다.

---

## 7. Arduino ↔ L298N 결선

Arduino Mega의 모터 제어 신호는 Arduino 확장보드를 거쳐 3개의 L298N Motor Driver로 연결된다.

```text
                 Arduino Mega 2560
                         │
                         ▼
                   Arduino 확장보드
                         │
            ┌────────────┼────────────┐
            │            │            │
            ▼            ▼            ▼
        L298N #1      L298N #2      L298N #3
```

각 L298N에는 Arduino에서 다음 종류의 제어 신호가 전달된다.

- ENA / ENB
- IN1 ~ IN4

상세 Arduino 핀 번호는 `03_Pinout_Table.md`에서 관리한다.

---

## 8. L298N #1 ↔ Linear Motor 1

L298N #1은 Linear Motor 1을 제어한다.

Motor 1은 L298N #1의 B Channel을 사용한다.

```text
Arduino 확장보드
        │
        ▼
    L298N #1
        │
        │ B Channel
        │ OUT3 / OUT4
        ▼
 Linear Motor 1
```

| Motor Driver | Channel | Output | Motor |
|---|---|---|---|
| L298N #1 | B | OUT3 / OUT4 | Motor 1 |

L298N #1의 A Channel은 사용하지 않는다.

---

## 9. L298N #2 ↔ Linear Motor 3 / 4

L298N #2는 Linear Motor 3과 Linear Motor 4를 제어한다.

```text
              L298N #2
               │     │
       A Channel     B Channel
          │              │
     OUT1 / OUT2     OUT3 / OUT4
          │              │
          ▼              ▼
       Motor 3         Motor 4
```

| Motor Driver | Channel | Output | Motor |
|---|---|---|---|
| L298N #2 | A | OUT1 / OUT2 | Motor 3 |
| L298N #2 | B | OUT3 / OUT4 | Motor 4 |

---

## 10. L298N #3 ↔ Linear Motor 2 / 5

L298N #3은 Linear Motor 2와 Linear Motor 5를 제어한다.

```text
              L298N #3
               │     │
       A Channel     B Channel
          │              │
     OUT1 / OUT2     OUT3 / OUT4
          │              │
          ▼              ▼
       Motor 5         Motor 2
```

| Motor Driver | Channel | Output | Motor |
|---|---|---|---|
| L298N #3 | A | OUT1 / OUT2 | Motor 5 |
| L298N #3 | B | OUT3 / OUT4 | Motor 2 |

---

## 11. Linear Motor 전체 결선

```text
Arduino Mega 2560
        │
        ▼
  Arduino 확장보드
        │
        ├──────────────→ L298N #1
        │                   │
        │                   └── OUT3 / OUT4 → Motor 1
        │
        ├──────────────→ L298N #2
        │                   │
        │                   ├── OUT1 / OUT2 → Motor 3
        │                   └── OUT3 / OUT4 → Motor 4
        │
        └──────────────→ L298N #3
                            │
                            ├── OUT1 / OUT2 → Motor 5
                            └── OUT3 / OUT4 → Motor 2
```

### 모터 연결 요약

| Linear Motor | Motor Driver | Channel | Output |
|---|---|---|---|
| Motor 1 | L298N #1 | B | OUT3 / OUT4 |
| Motor 2 | L298N #3 | B | OUT3 / OUT4 |
| Motor 3 | L298N #2 | A | OUT1 / OUT2 |
| Motor 4 | L298N #2 | B | OUT3 / OUT4 |
| Motor 5 | L298N #3 | A | OUT1 / OUT2 |

---

## 12. Raspberry Pi 3 ↔ U2D2 결선

Raspberry Pi 3와 U2D2는 USB로 연결한다.

```text
Raspberry Pi 3
      │
      │ USB
      ▼
    U2D2
```

U2D2는 Raspberry Pi와 DYNAMIXEL 사이의 통신 인터페이스로 사용한다.

---

## 13. U2D2 ↔ U2D2 Power Hub

U2D2와 U2D2 Power Hub는 3핀 케이블로 연결한다.

```text
U2D2
  │
  │ 3핀 케이블
  ▼
U2D2 Power Hub
```

U2D2 Power Hub에는 DYNAMIXEL 모터 구동용 별도 외부 전원을 연결한다.

> 외부 전원의 상세 구성은 `02_Power_Distribution_SMPS.md`에서 관리한다.

---

## 14. U2D2 Power Hub ↔ DYNAMIXEL

DYNAMIXEL XL430-W250-T 2개는 각각 U2D2 Power Hub에 3핀 케이블로 연결한다.

```text
             U2D2 Power Hub
               │        │
               │        │
          3핀 케이블   3핀 케이블
               │        │
               ▼        ▼
        DYNAMIXEL #1  DYNAMIXEL #2
```

### 연결 요약

| 시작 장치 | 연결 대상 | 연결 방식 |
|---|---|---|
| Raspberry Pi 3 | U2D2 | USB |
| U2D2 | U2D2 Power Hub | 3핀 케이블 |
| U2D2 Power Hub | DYNAMIXEL #1 | 3핀 케이블 |
| U2D2 Power Hub | DYNAMIXEL #2 | 3핀 케이블 |

---

## 15. DYNAMIXEL 전체 결선 구조

```text
Raspberry Pi 3
      │
      │ USB
      ▼
    U2D2
      │
      │ 3핀 케이블
      ▼
U2D2 Power Hub
      │
      ├── 3핀 케이블 ──→ DYNAMIXEL XL430-W250-T #1
      │
      └── 3핀 케이블 ──→ DYNAMIXEL XL430-W250-T #2

      ▲
      │
      └── 별도 외부 전원
```

Raspberry Pi USB와 DYNAMIXEL 구동용 외부 전원은 서로 역할이 다르다.

- Raspberry Pi ↔ U2D2 : USB 통신
- U2D2 ↔ Power Hub : DYNAMIXEL 통신
- 별도 외부 전원 → Power Hub : DYNAMIXEL 구동 전원
- Power Hub ↔ DYNAMIXEL : 통신 및 전원 전달

---

## 16. 전체 시스템 결선 요약

```text
Raspberry Pi 3
│
├── Breadboard
│      │
│      ├──→ I2C LCD 16×2
│      └──→ 4×4 Matrix Keypad
│
├── USB
│    │
│    └──→ Arduino Mega 2560
│              │
│              ▼
│        Arduino 확장보드
│              │
│              ├──→ HC-SR04
│              │
│              ├──→ L298N #1
│              │       └──→ Motor 1
│              │
│              ├──→ L298N #2
│              │       ├──→ Motor 3
│              │       └──→ Motor 4
│              │
│              └──→ L298N #3
│                      ├──→ Motor 5
│                      └──→ Motor 2
│
└── USB
     │
     └──→ U2D2
             │
             │ 3핀
             ▼
       U2D2 Power Hub
             │
             ├──→ DYNAMIXEL #1
             └──→ DYNAMIXEL #2
```

---

## 17. 주요 장치 결선 요약표

| 시작 장치 | 연결 대상 | 연결 방식 |
|---|---|---|
| Raspberry Pi 3 | Breadboard | GPIO / 전원 배선 |
| Breadboard | I2C LCD | I2C |
| Breadboard | 4×4 Matrix Keypad | GPIO |
| Raspberry Pi 3 | Arduino Mega 2560 | USB |
| Arduino Mega | Arduino 확장보드 | Board Direct Connection |
| Arduino 확장보드 | HC-SR04 | Signal / Power |
| Arduino 확장보드 | L298N #1 | Control Signal |
| Arduino 확장보드 | L298N #2 | Control Signal |
| Arduino 확장보드 | L298N #3 | Control Signal |
| L298N #1 | Motor 1 | OUT3 / OUT4 |
| L298N #2 | Motor 3 | OUT1 / OUT2 |
| L298N #2 | Motor 4 | OUT3 / OUT4 |
| L298N #3 | Motor 5 | OUT1 / OUT2 |
| L298N #3 | Motor 2 | OUT3 / OUT4 |
| Raspberry Pi 3 | U2D2 | USB |
| U2D2 | U2D2 Power Hub | 3핀 케이블 |
| U2D2 Power Hub | DYNAMIXEL #1 | 3핀 케이블 |
| U2D2 Power Hub | DYNAMIXEL #2 | 3핀 케이블 |

---

## 18. 문서 관리 기준

```text
electric/
├── 01_Wiring_Diagram.md
├── 02_Power_Distribution_SMPS.md
└── 03_Pinout_Table.md
```

### `01_Wiring_Diagram.md`

장치 간 실제 물리적 연결 관계를 관리한다.

- Breadboard
- Arduino 확장보드
- Raspberry Pi ↔ 주변 장치
- Raspberry Pi ↔ Arduino
- Arduino ↔ HC-SR04
- Arduino ↔ L298N
- L298N ↔ Linear Motor
- Raspberry Pi ↔ U2D2
- U2D2 ↔ Power Hub ↔ DYNAMIXEL

### `02_Power_Distribution_SMPS.md`

전원의 공급 및 분배 구조를 관리한다.

- Raspberry Pi 전원
- Arduino 전원
- HC-SR04 전원
- 12V SMPS
- L298N / Linear Motor 전원
- U2D2 Power Hub 외부 전원
- DYNAMIXEL 구동 전원

### `03_Pinout_Table.md`

실제 제어 핀 번호를 관리한다.

- Raspberry Pi GPIO
- LCD SDA / SCL
- Keypad ROW / COL
- Arduino Digital Pin
- HC-SR04 TRIG / ECHO
- L298N ENA / ENB
- L298N IN1 ~ IN4
- Motor별 제어 핀

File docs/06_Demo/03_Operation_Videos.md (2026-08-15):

키패드로 게스트 키 입력 시 시트 자동 변형 영상
초음파 센서 키 자동 측정 영상
임산부 모드 버튼 클릭 시 골반 벨트 위치 변경 영상

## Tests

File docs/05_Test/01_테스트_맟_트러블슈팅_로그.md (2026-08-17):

# 테스트 및 트러블슈팅 로그

개발 과정에서 실제로 겪고 해결한 문제들을 시간 순서와 무관하게 주제별로 정리했습니다. 심사 서류의 "개발 중 발생한 장애요인과 해결방안" 항목의 근거 자료로 활용합니다.

---

## 하드웨어

### 1. 스텝모터(NEMA17+DRV8825) 반복 소손
- **증상**: 확장보드 발연, GND/VMOT 점퍼선 용융 2회
- **원인**: 확정 못함(전류제한 미설정 추정)
- **해결**: 다이나믹셀 XL430 + U2D2로 전면 교체 (전류 제한 내장)

### 2. 스텝모터 구동 시 라즈베리파이 저전압 증상
- **증상**: 간헐적 USB 끊김, `Undervoltage detected!` — 스텝모터(NEMA17+DRV8825) 구동 중에만 발생
- **원인**: PD 어댑터 자체의 비호환 문제가 아니었음. 같은 어댑터(PD/고정 5V 겸용)가 이전·이후 모두 정상 동작 — 스텝모터 구동 시 전류 소모가 커지면서 공유 전원 계통 전압이 흔들린 것으로 추정
- **해결**: 스텝모터를 다이나믹셀로 교체한 뒤 증상이 완전히 사라짐. 별도의 전원 어댑터 교체는 필요 없었음 (원래 어댑터 그대로 사용 중)

### 3. 벨트 장기 미사용 후 토크 꺼짐
- **증상**: 여러 날 방치 후 재시작 시 홈 복귀 로그는 정상 출력되나 실제로 벨트가 움직이지 않음
- **원인**: 노드 종료(`destroy_node`) 시 토크가 꺼진 채로 유지됨
- **해결**: 재시작 전 토크 활성화 확인 절차 추가

---

## 소프트웨어 / 캘리브레이션

### 4. 벨트 tick-to-mm 비율이 비선형처럼 보임
- **증상**: 동일 틱 명령인데 실측 이동거리가 매번 다르게 나옴 (릴 슬립으로 오판)
- **원인**: 테스트 스크립트가 고정 관찰시간(4~6초) 후 목표 도달 전 강제로 토크를 끊음 — 하드웨어가 아니라 테스트 도구 자체의 결함
- **해결**: 목표 도착까지 대기(포지션 스톨 감지)하는 방식으로 스크립트 재작성
- **교훈**: 물리적 원인을 추정하기 전에 자체 코드/스크립트의 한계부터 배제할 것

### 5. USB 포트 번호(`/dev/ttyUSB0/1/2`) 유동성
- **증상**: 재연결·재부팅마다 포트 번호가 바뀌어 연결 실패 반복
- **해결**: `udev` 규칙(USB Vendor/Product ID + 시리얼 번호)으로 `/dev/arduino_linear`, `/dev/belt_u2d2` 고정

### 6. 리니어 액추에이터 물리적 배치 스왑
- **증상**: 150mm 위치 액추에이터가 실제로는 Arduino 모터 채널 2에, 320mm 위치가 채널 1에 연결됨(조립 실수)
- **해결**: 재배선 대신 `MOTOR_MAP = [2, 1, 3, 4, 5]`로 소프트웨어에서 보정

### 7. 벨트 홈 위치 드리프트
- **증상**: 디버깅 중 수동으로 벨트를 옮긴 뒤, 다음 명령에서 예상 밖 위치로 이동
- **원인**: 저장된 `belt_home.json` 기준값이 실제 물리적 홈과 어긋남
- **해결**: 손으로 재정렬 후 현재 raw 인코더 위치를 `belt_home.json`에 재기록하는 절차 확립

### 8. 동시 명령 경합(Race Condition)
- **증상**: 같은 프로필 버튼(예: B)을 연타하면 벨트가 매번 다른 위치로 이동
- **원인**: 매 입력마다 새 스레드가 동일한 Dynamixel `GroupSyncWrite` 객체에 동시 접근
- **해결**: `threading.Lock`으로 벨트 이동 명령 순차 실행 보장

### 9. 키패드 연장 케이블 유령 입력
- **증상**: 시작하자마자 D키가 저절로 눌린 것으로 인식, 특정 열/행(A/B/C/D 등)만 간헐적 오작동
- **원인**: 연장 케이블 커넥터 접촉 불량 (Row HIGH 시 여러 Col이 무작위로 동시 감지됨을 확인)
- **상태**: **진행중 대응** — 하드웨어(커넥터 고정)만으로 완전히 해결되지 않아, 소프트웨어로 다중 방어선 구축
  - 디바운스 4연속(200ms) 판정
  - 여러 열 동시 감지 시 유령 신호로 간주하고 무시
  - 부팅 후 1.5초간 키 입력 무시(전원 노이즈 구간 회피)
  - 게스트 모드 오진입 시 프로필 키 입력으로 자동 복구 (`guest_mode.md` 참고)
- **남은 과제**: 커넥터 납땜 고정 또는 케이블 교체로 근본 해결 필요

---

## 검증 방법 메모

### 벨트 캘리브레이션 검증
알려진 높이의 물체를 방석 위 특정 지점에 놓고 측정값과 비교하는 방식으로 `BELT_TICKS_PER_MM`, `BELT_CALIBRATION_OFFSET_MM` 상수를 실측 검증했습니다.

### 초음파 센서 시연 거리표
실제 사람이 2:1 축소 모형에 앉을 수 없으므로, 목표 키(cm)별로 손/물체를 놓아야 할 센서-대상 거리(mm)를 미리 계산해두고 시연에 사용합니다.

| 목표 키(cm) | 센서-대상 거리(mm) |
|---|---|
| 130 | 약 198 |
| 150 | 약 155 |
| 170 | 약 112 |
| 178 | 약 95 |
| 185 | 약 80 |

계산식은 `Seat_Control_Algorithm.md` 4절 참고.

---

## TODO — 하드웨어 재접근 시 재검증할 것

- [ ] 키패드 연장 케이블 근본 해결 여부 확인 (납땜/교체)
- [ ] 벨트 A/B/C 목표값 재검증 (자로 재측정)
- [ ] 초음파 센서 실제 사람 대상 정확도 재확인
- [ ] HC-SR04 ECHO 레벨시프트 회로 확인

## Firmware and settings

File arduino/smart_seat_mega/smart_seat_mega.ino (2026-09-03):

/*
 * Smart Seat - Arduino Mega 2560
 * 역할: 라즈베리파이(ROS 2)의 명령을 받아
 *       (1) 리니어 액추에이터 5개(L298N x3) 구동
 *       (2) HC-SR04 초음파 센서로 거리 측정 후 회신
 *
 * 통신: USB Serial 115200bps
 *   - 모터 명령 : "M,<번호>,<방향>,<속도>"   예) M,1,1,200
 *       방향 1=전진(늘림) / -1=후진(줄임) / 0=정지,  속도 0~255
 *       응답 : "OK M1 dir=1 spd=200"
 *   - 거리 요청 : "U"
 *       응답 : "DIST,<거리_mm>"   (측정 실패 시 "DIST,-1")
 *
 * 초음파 이설 배경:
 *   HC-SR04 ECHO는 5V 출력이라 3.3V인 라즈베리파이 GPIO에 직결하면 위험하다.
 *   5V 로직인 아두이노에서 직접 읽으면 레벨시프트(저항분배) 회로가 불필요하고
 *   펄스 타이밍도 안정적으로 처리된다.
 *   ※ TRIG/ECHO 핀 번호는 배선에 맞춰 자유롭게 변경 가능(아래 상수만 수정).
 */

// ── 리니어 액추에이터 (L298N x3) ──
const int NUM_MOTORS = 5;
const int MOTOR_EN[NUM_MOTORS] = { 2, 3, 4, 5, 6 };      // EN(PWM)
const int MOTOR_IN[NUM_MOTORS][2] = {
  {22, 23},   // 모터1 (L298N#1 A)
  {24, 25},   // 모터2 (L298N#1 B)
  {26, 27},   // 모터3 (L298N#2 A)
  {28, 29},   // 모터4 (L298N#2 B)
  {30, 31},   // 모터5 (L298N#3 A)
};

// ── HC-SR04 초음파 센서 (아두이노 5V 로직에서 직접 읽음) ──
// 리니어용 D2~D6, D22~D31 과 겹치지 않는 여유 핀 사용. 배선에 맞게 변경 가능.
const int TRIG_PIN = 7;
const int ECHO_PIN = 8;
const unsigned long ECHO_TIMEOUT_US = 30000UL;  // 약 5m 왕복 타임아웃

void setup() {
  Serial.begin(115200);

  for (int i = 0; i < NUM_MOTORS; i++) {
    pinMode(MOTOR_EN[i], OUTPUT);
    pinMode(MOTOR_IN[i][0], OUTPUT);
    pinMode(MOTOR_IN[i][1], OUTPUT);
    stopMotor(i);   // 시작 시 전부 정지 (안전)
  }

  pinMode(TRIG_PIN, OUTPUT);
  pinMode(ECHO_PIN, INPUT);
  digitalWrite(TRIG_PIN, LOW);

  Serial.println("READY");
}

void loop() {
  if (Serial.available() > 0) {
    String cmd = Serial.readStringUntil('\n');
    cmd.trim();
    handleCommand(cmd);
  }
}

void handleCommand(String cmd) {
  if (cmd.length() == 0) return;

  char type = cmd.charAt(0);

  // ── 거리 요청: "U" ──
  if (type == 'U') {
    long mm = readUltrasonicMM();
    Serial.print("DIST,");
    Serial.println(mm);   // 실패 시 -1
    return;
  }

  // ── 모터 명령: "M,번호,방향,속도" ──
  if (type == 'M') {
    int c1 = cmd.indexOf(',');
    int c2 = cmd.indexOf(',', c1 + 1);
    int c3 = cmd.indexOf(',', c2 + 1);
    if (c1 < 0 || c2 < 0 || c3 < 0) return;

    int motorNum = cmd.substring(c1 + 1, c2).toInt();  // 1~5
    int dir      = cmd.substring(c2 + 1, c3).toInt();  // 1/0/-1
    int speed    = cmd.substring(c3 + 1).toInt();      // 0~255

    int idx = motorNum - 1;
    if (idx < 0 || idx >= NUM_MOTORS) return;

    driveMotor(idx, dir, speed);

    Serial.print("OK M"); Serial.print(motorNum);
    Serial.print(" dir="); Serial.print(dir);
    Serial.print(" spd="); Serial.println(speed);
  }
}

// HC-SR04 왕복 시간 → 거리(mm). 실패 시 -1 반환.
long readUltrasonicMM() {
  digitalWrite(TRIG_PIN, LOW);
  delayMicroseconds(2);
  digitalWrite(TRIG_PIN, HIGH);
  delayMicroseconds(10);
  digitalWrite(TRIG_PIN, LOW);

  unsigned long duration = pulseIn(ECHO_PIN, HIGH, ECHO_TIMEOUT_US);
  if (duration == 0) return -1;              // 타임아웃(측정 실패)

  // 음속 343m/s → 편도거리(mm) = duration(us) * 0.343 / 2
  long distance_mm = (long)(duration * 0.343 / 2.0);
  return distance_mm;
}

void driveMotor(int idx, int dir, int speed) {
  speed = constrain(speed, 0, 255);
  if (dir > 0) {          // 전진(늘림)
    digitalWrite(MOTOR_IN[idx][0], HIGH);
    digitalWrite(MOTOR_IN[idx][1], LOW);
    analogWrite(MOTOR_EN[idx], speed);
  } else if (dir < 0) {   // 후진(줄임)
    digitalWrite(MOTOR_IN[idx][0], LOW);
    digitalWrite(MOTOR_IN[idx][1], HIGH);
    analogWrite(MOTOR_EN[idx], speed);
  } else {                // 정지
    stopMotor(idx);
  }
}

void stopMotor(int idx) {
  digitalWrite(MOTOR_IN[idx][0], LOW);
  digitalWrite(MOTOR_IN[idx][1], LOW);
  analogWrite(MOTOR_EN[idx], 0);
}

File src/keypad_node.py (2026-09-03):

#!/usr/bin/env python3
import rclpy
from rclpy.node import Node
from geometry_msgs.msg import Point
import RPi.GPIO as GPIO
import time
import threading
import json
import os
from RPLCD.i2c import CharLCD


PROFILE_PATH = os.path.expanduser('~/ros2_ws/src/smart_seat/profiles.json')


class SmartSeatController(Node):
    def __init__(self):
        super().__init__('keypad_node')
        self.get_logger().info('keypad_node 시작됨 (복구본)')

        self.profiles = self.load_profiles()

        try:
            self.lcd = CharLCD('PCF8574', 0x27, cols=16, rows=2, auto_linebreaks=False)
            self.lcd.clear()
            self.lcd.write_string("Family Seat\nReady...")
            self.get_logger().info('LCD Initialized Successfully (0x27)')
        except Exception as e:
            self.get_logger().error(f'LCD Init Failed: {e}')
            self.lcd = None

        self.pub = self.create_publisher(Point, '/body_data', 10)

        GPIO.setmode(GPIO.BCM)
        GPIO.setwarnings(False)
        self.ROW_PINS = [5, 6, 13, 19]
        self.COL_PINS = [26, 12, 16, 20]
        self.KEY_MAP = [
            ['C', '.', '7', '3'],
            ['D', 'E', '8', '4'],
            ['B', '0', '6', '2'],
            ['A', '9', '5', '1'],
        ]
        for pin in self.ROW_PINS:
            GPIO.setup(pin, GPIO.OUT)
            GPIO.output(pin, GPIO.LOW)
        for pin in self.COL_PINS:
            GPIO.setup(pin, GPIO.IN, pull_up_down=GPIO.PUD_DOWN)

        self.guest_mode_active = False
        self.input_buffer = ""
        self.last_key = None
        self.d_press_time = None
        self.d_long_fired = False
        self.LONGPRESS_SEC = 3.0

        # 초음파 센서 (HC-SR04)
        self.TRIG_PIN = 23
        self.ECHO_PIN = 24
        GPIO.setup(self.TRIG_PIN, GPIO.OUT)
        GPIO.setup(self.ECHO_PIN, GPIO.IN)
        GPIO.output(self.TRIG_PIN, GPIO.LOW)

        self.SENSOR_HEIGHT_ABOVE_CUSHION_MM = 570.0
        self.SIT_A, self.SIT_B, self.SIT_C = 4.2999, 0.2129, 171.2187
        self.GUEST_WEIGHT_KG = 65.0

        # 키패드 디바운스 / 유령신호 방지
        self._debounce_candidate = None
        self._debounce_count = 0
        self.DEBOUNCE_THRESHOLD = 2

        # 부팅 워밍업 (전원 노이즈로 인한 유령 D 입력 방지)
        self.BOOT_WARMUP_SEC = 1.5
        self.boot_time = time.time()

        self.timer = self.create_timer(0.05, self.scan_keypad)

        # 시작 시 자동 리셋 (벨트처럼 부팅할 때 한 번 확실히 정렬)
        threading.Timer(self.BOOT_WARMUP_SEC + 0.5, self.send_reset).start()

    def load_profiles(self):
        try:
            with open(PROFILE_PATH, 'r', encoding='utf-8') as f:
                data = json.load(f)
            self.get_logger().info(f'프로필 로드 성공: {list(data.keys())}')
            return data
        except Exception as e:
            self.get_logger().error(f'프로필 로드 실패, 기본값 사용: {e}')
            return {
                "A": {"name": "PAPA", "height": 178, "pregnant": False},
                "B": {"name": "MAMA", "height": 162, "pregnant": True},
                "C": {"name": "DAUGHTER", "height": 130, "pregnant": False},
            }

    def scan_keypad(self):
        # 부팅 직후 노이즈 구간 무시
        if time.time() - self.boot_time < self.BOOT_WARMUP_SEC:
            return

        pressed_keys = []
        for r_idx, r_pin in enumerate(self.ROW_PINS):
            GPIO.output(r_pin, GPIO.HIGH)
            for c_idx, c_pin in enumerate(self.COL_PINS):
                if GPIO.input(c_pin) == GPIO.HIGH:
                    pressed_keys.append(self.KEY_MAP[r_idx][c_idx])
            GPIO.output(r_pin, GPIO.LOW)

        if len(pressed_keys) > 1:
            # 여러 키 동시 감지 = 접점 불량 유령 신호로 판단, 무시
            self._debounce_candidate = None
            self._debounce_count = 0
            return

        pressed_key = pressed_keys[0] if pressed_keys else None

        if pressed_key == self._debounce_candidate:
            self._debounce_count += 1
        else:
            self._debounce_candidate = pressed_key
            self._debounce_count = 1

        if self._debounce_count < self.DEBOUNCE_THRESHOLD:
            return
        key = self._debounce_candidate

        if True:  # D 롱프레스/짧은클릭은 게스트모드 여부와 무관하게 항상 동작
            if key == 'D':
                if self.last_key != 'D':
                    self.d_press_time = time.time()
                    self.d_long_fired = False
                    self.get_logger().info('D 버튼 눌림 → 롱프레스 타이머 시작')
                elif not self.d_long_fired and self.d_press_time is not None and (time.time() - self.d_press_time) >= self.LONGPRESS_SEC:
                    self.d_long_fired = True
                    self.get_logger().info('D 3초 이상 입력 → 초음파 자동 측정 시작')
                    self.measure_height_ultrasonic()
                self.last_key = key
                self.d_last_seen_time = time.time()
                return
            elif self.last_key == 'D' and key != 'D':
                if self.d_press_time is not None and (time.time() - getattr(self, 'd_last_seen_time', 0)) < 0.3:
                    if not self.d_long_fired and (time.time() - self.d_press_time) >= self.LONGPRESS_SEC:
                        self.d_long_fired = True
                        self.measure_height_ultrasonic()
                    return
                if not self.d_long_fired:
                    self.process_key('D')
                self.d_press_time = None
                self.last_key = key
                return

        if key != self.last_key:
            self.last_key = key
            if key is not None:
                self.process_key(key)

    def process_key(self, key):
        self.get_logger().info(f'Key Pressed: {key}')
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

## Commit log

2026-08-09 Create 하드웨어
2026-08-09 Create 소프트웨어
2026-08-09 Create 테스트
2026-08-09 Create 데모
2026-08-09 Create C++ 소스 코드 또는 ROS Node 핵심 로직)
2026-08-09 Create (Python 스크립트, 센서 모듈, UI알고리즘)
2026-08-09 Create (시스템 전체 실행 파일 - ROS 사용 시)
2026-08-14 Create assemble
2026-08-14 Create PINMAP.md for Smart Seat System
    Added detailed pin mapping and system architecture for the Smart Seat System, including connections between Raspberry Pi, Arduino Mega, and L298N motor drivers.
2026-08-14 파일 명 바꿈
    일단 리니어모터랑만 해놓음 다이나믹셀 핀맵은 못찾음
2026-08-15 Rename 하드웨어 to 하드웨어 사용 부품 목록표.
2026-08-15 Ros 노드 간의 Topic/Service 구조 통신도
2026-08-15 아두이노 우노와 라즈베리파이 간의 시리얼 데이터 패킷 구조 및 통신 주기 정의
2026-08-15 신장 데이터 입력시 리니어 모터 스트로크 및 다이나믹셀 엔코더 계산 공식
2026-08-15 Create 전원계통도 및 전체 결선도 통합
2026-08-15 테스트 과정을 보여주는 공간
    Documented tests for power stability, input response, control precision, and operation timing.
2026-08-15 하드웨어. 소프트웨어, 전원 구조가 포함된 한 눈에 보는 시스템 구상도
2026-08-15 Create Hardware Photos
    smps 아두이노 라즈베리파이 모터드라이버가 배선된 회로 박스 및 시트 실물 사진
2026-08-15 Create profile manager for JSON/DB data
    Add family profile key, waist curve position, and belt height management.
2026-08-15 Implement guest mode functionality
    Add functionality to convert manual input or ultrasonic sensor measurements to sheet target control values.
2026-08-15 Implement noise filtering for ultrasonic sensor
    Add noise filtering for ultrasonic sensor data.
2026-08-15 Create Seat Gui for touchscreen display
    Add UI for Raspberry Pi touchscreen monitor.
2026-08-15 Rename Seat Gui to 고민중 발전방향을 ㅇ터디에다해야하지
2026-08-15 Update 고민중 발전방향을 ㅇ터디에다해야하지
2026-08-15 Rename 전원계통도 및 전체 결선도 통합 to git mv전원계통도 및 전체 결선도 통합
2026-08-15 Rename git mv "전원계통도 및 전체 결선도 통합" to 전원계통도_및_전체_결선도_통합.md
2026-08-15 Rename Arduino Ros Protocol to Arduino_Ros_Protocol.md
2026-08-15 Rename ultrasonic filter to ultrasonic_filter.md
2026-08-15 Create hardware components list (BOM)
    Added detailed hardware components list including specifications and roles for each item. Included TODOs for further verification of certain items.
2026-08-15 Document ultrasonic filter logic and measurement principles
    Added detailed documentation for ultrasonic sensor noise filtering logic, including measurement principles and noise defense strategies.
2026-08-15 허리부분 수정
    키패드 Lcd 얘네는 아직 안넣음
2026-08-15 1차 결선도
2026-08-15 1차 전원 계통도
    Document the power distribution system for the smart sheet system, including motor power and control circuits.
2026-08-15 1차결선도
    키패드랑 딴 거 핀맵 후 추가할예정
2026-08-16 folder rearrange
    [backrest_outer_frame.step, backrest_outer_frame.stl, backrest_shell.step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]
2026-08-16 Revise Raspberry Pi undervoltage section in log
    Updated troubleshooting log for Raspberry Pi undervoltage issue during stepper motor operation, including symptoms, causes, and solutions.
2026-08-17 Rename C++ 소스 코드 또는 ROS Node 핵심 로직) to CMakeLists.txt
2026-08-17 Update electrical README with power supply details
2026-08-18 개발일정표
2026-08-18 사진 첨부 및 표 도식화
2026-08-18 버전 2
2026-08-18 Delete 스마트 시트 개발 일정
    Removed the entire development schedule for the smart sheet project.
2026-08-18 2차 전원 계통도
    Update power distribution details for Raspberry Pi and motor systems.
2026-08-18 3차 전원계통도
2026-08-25 Revise Smart Seat System pinout table
    Updated the pinout table for the Smart Seat System, including device roles and connections for Raspberry Pi, Arduino Mega, and L298N motor drivers.
2026-08-25 다이나믹셀 없음
2026-08-25 다이나믹셀 포함
2026-08-25 다이나믹셀 포함 수정
    Updated the power distribution documentation for the smart sheet system, including detailed descriptions of the power supply structure, components, and connections.
2026-08-25 Update U2D2 Power Hub diagram in documentation
2026-08-25 다이나믹셀 추가
    Updated the pinout documentation for the smart sheet system, including detailed connections for Raspberry Pi 4, Arduino Mega 2560, I2C LCD, and linear motors.
2026-08-25 Revise pinout table and system configuration details
    Updated the pinout documentation for the smart sheet system, correcting device references and enhancing clarity.
2026-08-25 모터 위치 수정
2026-08-26 Implement seat controller node with motor control
2026-08-27 Add README.md for demo materials and resources
2026-08-27 Update 개발 일정표.md
2026-08-27 Update 개발 일정표-2.md
2026-08-30 Fix motor mapping to 1-5; move ultrasonic to Arduino; add .ino, profiles/belt_home json
    [arduino_bridge_node.py, keypad_node.py, seat_controller_node.py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]
2026-08-30 Refactor ultrasonic measurement to use Arduino bridge
    Refactor ultrasonic distance measurement to use Arduino instead of direct GPIO. Added publisher and subscriber for distance requests and responses.
2026-08-30 Remove Arduino bridge node implementation
2026-08-30 Add ultrasonic distance measurement functionality
2026-08-30 Fix motor mapping for seat controller
    Updated motor mapping to reflect physical wiring changes.
    [seat_controller_node.py]
2026-08-30 Remove comments and documentation from smart_seat_mega.ino
    Removed commented-out code and documentation for the Smart Seat Arduino Mega project.
2026-08-30 Implement smart seat control with actuators and sensor
    This code controls a smart seat using an Arduino Mega 2560. It manages five linear actuators and measures distance with an HC-SR04 ultrasonic sensor, communicating via USB Serial.
2026-08-30 Delete belt_home.json
    Remove belt_home.json configuration file.
2026-08-30 Add belt_home.json with initial configuration values
2026-09-02 Revise wiring documentation for Raspberry Pi and Arduino
    Refactor and update connections for Raspberry Pi 3, Arduino Mega, and motor drivers. Remove unnecessary sections and clarify wiring details.
2026-09-02 Revise pinout table and wiring diagram
    Updated the pinout table and overall wiring diagram for the smart sheet system, including detailed connections for Raspberry Pi, Arduino Mega, and other components.
2026-09-02 Revise Smart Seat System Wiring Diagram
    Updated the wiring diagram for the Smart Seat System to include detailed connections and device specifications.
2026-09-03 Refactor BeltControllerNode to SeatControllerNode
2026-09-03 Remove ultrasonic distance measurement functionality
    Removed measurement request subscription and publisher for ultrasonic distance.
2026-09-03 Update TRIG_PIN and ECHO_PIN for ultrasonic sensor
    Changed TRIG_PIN and ECHO_PIN to new GPIO pins.

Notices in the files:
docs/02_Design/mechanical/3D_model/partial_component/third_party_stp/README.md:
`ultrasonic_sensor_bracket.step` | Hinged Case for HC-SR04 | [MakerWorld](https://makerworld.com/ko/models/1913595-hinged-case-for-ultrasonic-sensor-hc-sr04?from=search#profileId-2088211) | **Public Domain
